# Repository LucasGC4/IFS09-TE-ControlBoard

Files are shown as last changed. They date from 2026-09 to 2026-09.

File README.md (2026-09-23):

isc-full-primary

# IFS09-TE-ControlBoard

Hardware design and KiCad schematics/PCB layout for the **Control Board (ECU Node)** of the **IFS09**, developed for the **ISC Formula Student Racing Team** (Season 2026/2027). This is a first onboarding project for the Electronics & Control subsystem — the board's mission is to become the vehicle's ECU node, reading dual CAN buses and analog/digital sensors from the AMPSEAL car harness.


[]()
[]()
[]()
[]()




---

## Getting started

1. Create a GitHub account if you don't have one yet.
2. Download and install [GitHub Desktop](https://desktop.github.com/) (beginner) or [Git CLI](https://git-scm.com/book/en/v2/Getting-Started-Installing-Git) (advanced).
3. Install [KiCad 10](https://www.kicad.org/download/) (or latest stable) and, if needed, link the team's shared library [`IFS-KicadLib`](https://github.com/isc-fs/IFS-KicadLib) for team-standard symbols and footprints.
4. Clone this repository to your machine:
   - **SSH:** `git@github.com:LucasGC4/IFS09-TE-ControlBoard.git`
   - **HTTPS:** `https://github.com/LucasGC4/IFS09-TE-ControlBoard.git`

---

## How we work with this repository

Following ISC's standard branching rules:

* **`main`** holds only validated releases. Never commit directly to it.
* Active design work happens on feature branches (`feat/<name>`, `fix/<name>`) created from `main`, merged back through a reviewed Pull Request.

```bash
git checkout main
git pull origin main
git checkout -b feat/your-feature-name
# ... work and commit ...
git commit -m "hw: add CAN2 split termination network"
git push origin feat/your-feature-name
```

Before opening a PR: verify **0 KiCad ERC/DRC errors** and export an updated `Schematics-X.X.pdf`.

---

## 1. Project Overview & System Purpose

The **IFS09 Control Board** is an automotive-grade microcontroller node connected to the car's 24V Low Voltage battery and both CAN communication buses, intended to read sensors and drive vehicle actuators.

```
+------------------------------------------------------------------------+
|                    IFS09 CAR WIRING HARNESS                            |
|   +24V LV Battery -- CAN1 -- CAN2 -- 2x Digital In -- 2x Analog In     |
+---------------------------------+----------------------------------------+
                                  |
                     AMPSEAL 14-Pin (J1, 1-776087-1)
                                  |
+---------------------------------v----------------------------------------+
|                       IFS09 CONTROL BOARD (ECU NODE)                    |
|                                                                          |
|  +24V --> [TSR 1-2450 Buck, U1] --> 5V --> [LM2936-3.3 LDO, U2] --> 3V3 |
|                                                                          |
|  CAN1 <--> [TCAN330, U3] --\                                           |
|                              >--- SPI/GPIO ---> [STM32H7A3IGTxQ, U4]    |
|  CAN2 <--> [TCAN330, U5] --/            (LQFP-176, 16 MHz osc. Y1)      |
|                                                                          |
|  Status LEDs (24V/5V/3.3V/Heartbeat) · SWD (J4) · UART+I2C (J2) · SPI (J3) |
+--------------------------------------------------------------------------+
```

### Key Highlights
* **Processing:** STM32H7A3IGTxQ (LQFP-176) with a 16 MHz active oscillator (`Y1`, XUX53) with isolated ground plane.
* **Power chain:** 24V → 5V via `U1` (TSR 1-2450 DC/DC module, fused with `F1` 2A), then 5V → 3.3V via `U2` (LM2936-3.3, TO-92).
* **CAN interfaces:** Two independent `TCAN330` transceivers (`U3` for CAN1, `U5` for CAN2), each with a 120 Ω bus termination resistor (`R5`, `R6`) and 100 nF decoupling.
* **Vehicle connector:** Single AMPSEAL-style 23-position header (`J1`, part `1-776087-1`) carries +24V, GND, CAN1, CAN2, and a 3V3 line to/from the harness.
* **Decoupling:** A bank of ~40 ceramic capacitors (mostly 100 nF, plus bulk caps) placed across the MCU's `VDD`/`VDDA` pins.
* **Diagnostics:** Four status LEDs (24V, 5V, 3.3V, Heartbeat) and four test points (`TP1`–`TP4`).
* **Debug/expansion headers:** `J4` (SWD), `J2` (UART + I²C), `J3` (SPI) — see pinout below.
* **Mechanical:** Four mounting holes (`H1`–`H4`), rounded-corner outline, 2-layer PCB (`F.Cu`/`B.Cu`).

---

## 2. Hardware Architecture & Schematic Design

The schematic export is available as [`Schematics.pdf`](Schematics.pdf), organized into labeled functional blocks matching the sections below.

### 2.1 Schematic Subsystem Breakdown

#### 1. Power Converters (24V → 5V → 3.3V)
* `F1` (2A fuse) protects the +24V input line.
* `U1` — **TSR 1-2450** DC/DC converter module steps 24V down to 5V, with `C3`/`C4` (10 µF) at input/output.
* `U2` — **LM2936-3.3 (TO-92)** LDO regulates 5V down to a clean 3.3V rail, with `C1`/`C2` (10 nF/100 nF) decoupling.

#### 2. Microcontroller (`U4` — STM32H7A3IGTxQ, LQFP-176)
* Clocked by a 16 MHz active oscillator (`Y1`, XUX53) placed in its own labeled section for ground isolation.
* Reset circuit: push button `SW1` with debounce capacitor `C11` (100 nF) and pull-up `R9` (10 kΩ) on `NRST`.
* `VCAP` pins filtered with `C6`/`C8` (2.2 µF).
* A large bank of decoupling capacitors (`C12`–`C55` range, mostly 100 nF, plus one 4.7 µF bulk cap) covers the MCU's power pins.

#### 3. Dual CAN Transceivers (`U3`, `U5` — TCAN330)
* `U3` interfaces `CAN1_TX`/`CAN1_RX` from the MCU to `CAN1_H`/`CAN1_L`, terminated by `R5` (120 Ω).
* `U5` interfaces `CAN2_TX`/`CAN2_RX` to `CAN2_H`/`CAN2_L`, terminated by `R6` (120 Ω).
* Each transceiver has its own 100 nF decoupling capacitor (`C9`, `C10`).

#### 4. Status LEDs & Test Points
* `D1`/`R1` (10 kΩ) — 24V rail indicator.
* `D2`/`R2` (1 kΩ) — 5V rail indicator.
* `D3`/`R3` (680 Ω) — 3.3V rail indicator.
* `D4`/`R4` (1 kΩ) — Heartbeat LED driven by the MCU.
* `TP1`–`TP4` — test points for the four rails/signals shown above.

---

## 3. PCB Layout & Physical Implementation

<p align="center">
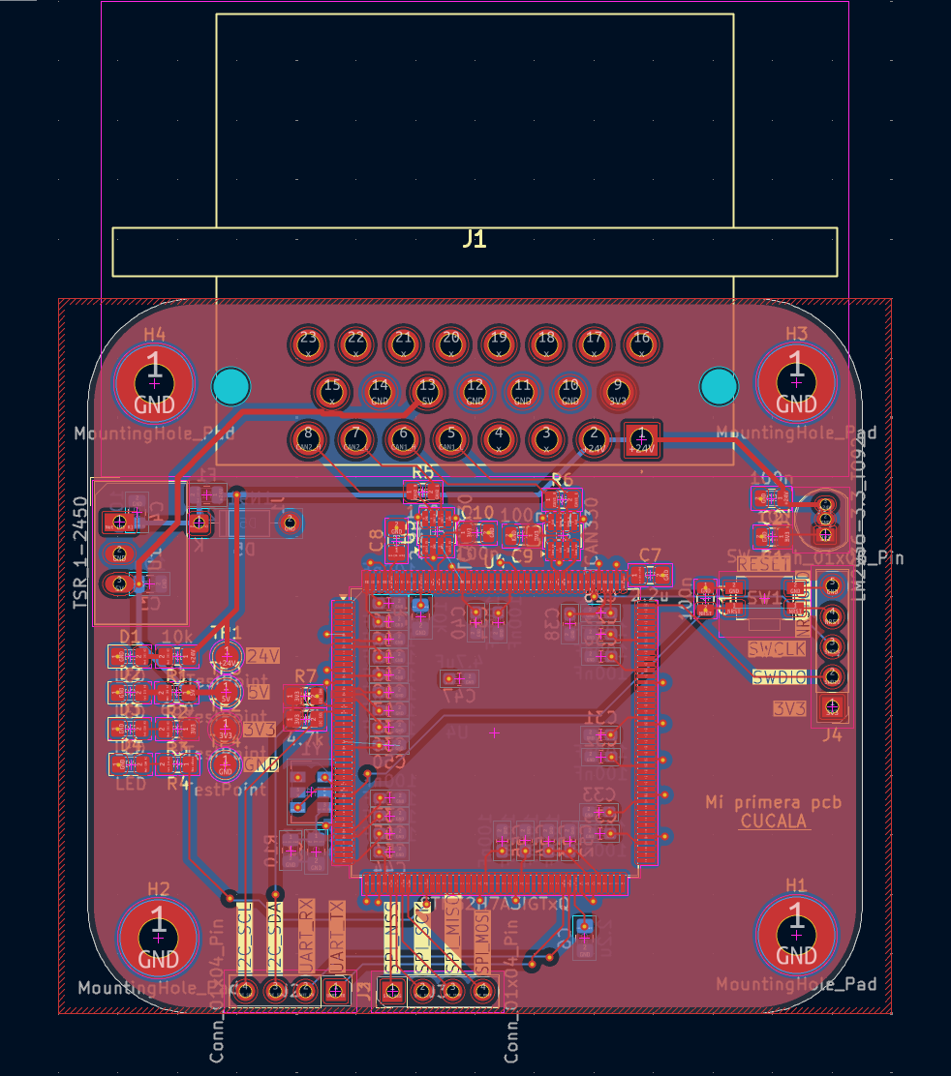
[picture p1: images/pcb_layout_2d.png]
IFS09 Control Board 2D PCB Layout
  
  &nbsp;&nbsp;&nbsp;&nbsp;
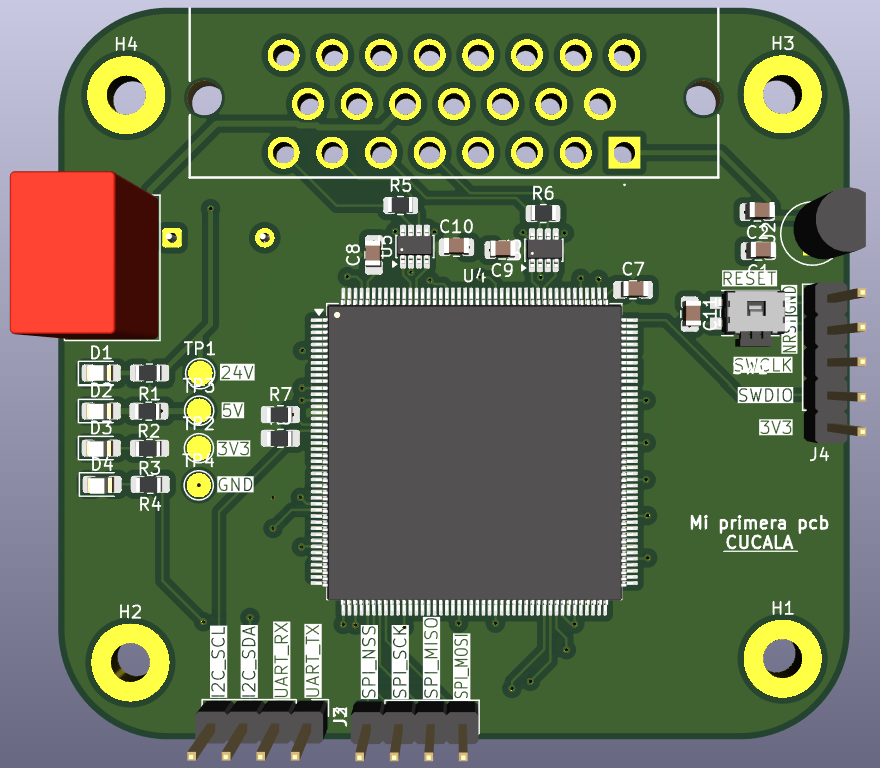
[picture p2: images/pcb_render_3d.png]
IFS09 Control Board 3D Render
  
</p>

* 2-layer board (`F.Cu` / `B.Cu`), rounded-corner outline, four M3-class mounting holes (`H1`–`H4`) at the corners.
* `J1` (AMPSEAL) is placed along the top edge for direct harness mating; the MCU (`U4`) sits centrally with debug/expansion headers (`J2`, `J3`, `J4`) broken out along the bottom edge.

---

## 4. Pinout & Hardware Interfacing

### 4.1 Vehicle Connector — `J1` (`1-776087-1`, AMPSEAL-style, 23-position)

| Pin(s) | Signal | Notes |
| :--- | :--- | :--- |
| 1, 2 | `+24V` | Battery input (tied together) |
| 5 | `CAN1_L` | CAN Bus 1 |
| 6 | `CAN1_H` | CAN Bus 1 |
| 7 | `CAN2_L` | CAN Bus 2 |
| 8 | `CAN2_H` | CAN Bus 2 |
| 9 | `3V3` | 3.3V line to/from harness |
| 10, 11 | `GND` | Ground |
| 13 | `5V` | 5V output |
| 14 | `GND` | Ground |
| 3, 4, 15–23 | *NC* | Not connected in this revision |

### 4.2 Debug & Expansion Headers

| Header | Type | Pin 1 | Pin 2 | Pin 3 | Pin 4 | Pin 5 |
| :--- | :--- | :--- | :--- | :--- | :--- | :--- |
| `J4` | SWD (5-pin) | `3V3` | `SWDIO` | `SWCLK` | `NRST` | `GND` |
| `J2` | UART + I²C (4-pin) | `UART_TX` | `UART_RX` | `I2C_SDA` | `I2C_SCL` | — |
| `J3` | SPI (4-pin) | `SPI_NSS` | `SPI_SCK` | `SPI_MISO` | `SPI_MOSI` | — |

> I²C lines (`I2C_SDA`/`I2C_SCL`) are pulled up to 3V3 via `R7`/`R8` (4.7 kΩ each).

---

## 5. Repository Structure

```
IFS09-TE-ControlBoard/
├── images/                                  # PCB layout/render exports
│   ├── pcb_layout_2d.png                    # 2D PCB Layout Routing View
│   └── pcb_render_3d.png                    # 3D PCB Render Model
├── IFS09-ControlBoard/                      # KiCad Project Files (KiCad 10.x)
│   ├── IFS09-ControlBoard.kicad_pro         # Project Configuration
│   ├── IFS09-ControlBoard.kicad_sch         # Schematic Sheet
│   └── IFS09-ControlBoard.kicad_pcb         # PCB Layout & Netlist
├── WO_TE-IFS09-ControlBoard (1).pdf         # Work Order / onboarding brief (Rev 1.1)
├── Schematics.pdf                           # Exported schematic sheet
└── README.md                                # This file
```

> **Not yet in the repository:** a Design Report (`DR_TE-IFS09-ControlBoard.pdf`) and a `SW/` firmware folder — both are still pending, per the Work Order's submission checklist.

---

## 6. Formal Design Documents

| Document | File Link | Description | Status |
| :--- | :--- | :--- | :--- |
| **Work Order** | [📄 WO_TE-IFS09-ControlBoard (1).pdf](<WO_TE-IFS09-ControlBoard (1).pdf>) | Onboarding roadmap, requirements, and pinout brief (Rev 1.1). | **Released** |
| **Schematics** | [📄 Schematics.pdf](Schematics.pdf) | Exported schematic sheet. | Current |
| **Design Report** | *(not yet created)* | Component justifications, BOM, and post-assembly test results. | **Pending** |

---

## 7. Acceptance Testing Checklist (Post-Assembly Bench QA)

As defined in the Work Order, once the board is assembled:

1. **Passive short-circuit check:** resistance from each supply test point to `GND` must read **> 10 kΩ** before power-up.
2. **Power-up & regulation:** with a 24V bench supply (current-limited to 200 mA), verify `TP2` (5V) = 5.0 V ± 0.2 V and `TP3` (3.3V) = 3.3 V ± 0.05 V, and that all power LEDs light up.
3. **SWD detection & MCU flash:** connect ST-Link to `J4` and flash test firmware to blink the Heartbeat LED (`D4`).
4. **Dual CAN loopback:** connect `CAN1`/`CAN2` to a USB-CAN adapter (PCAN/CANable) and verify send/receive at 500 kbit/s with zero dropped frames.
5. **Bus probing:** check `SPI` (`J3`) and `UART`/`I2C` (`J2`) lines with an oscilloscope for clean signals.

---

## 8. Author & Credits

* **Subsystem:** Electronics & Control (CE)
* **Author:** Lucas García Cucala
* **Mentorship & Review:** Carlota Treviño, Félix González, Inés Pacheco, Andrés Sánchez de Ágreda
* **Team:** [ISC Formula Student Racing Team](https://www.comillas.edu/) — Universidad Pontificia Comillas (ICAI)
* **Season:** 2026 / 2027

---

*ISC Racing Team — IFS09 Electronics & Control Subsystem*

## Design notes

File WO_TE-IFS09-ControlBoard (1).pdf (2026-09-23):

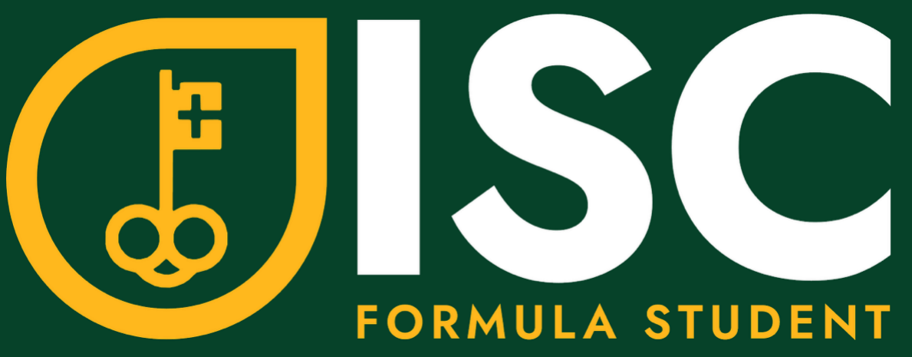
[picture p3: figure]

### Season 2026/2027

# Work Order – IFS09 Control Board

Department: Electronics & Control
Author: Andrés Sánchez, Carlota Treviño & Inés Pacheco Date: 3 September 2026
Revision: 1.1 (Onboarding Edition)

CONFIDENTIALITY NOTICE: the contents of this document are intended solely for use within the team and its members, may contain confidential or privileged information and may be legally protected from disclosure.

ISC Formula Student Racing Team © | Page 1
DOCUMENT ID: WO-IFS09-CTRL-001 | ELECTRONICS ONBOARDING & KICAD SCHEMATIC GUIDE

# 1. Welcome to ISC Electronics: The Journey from Mingo to Tronik

Welcome to the ISC Electronics & Control Subsystem! If you are reading this, your journey from the introductory recruitment phase ('Mingo') to designing real competition embedded electronic hardware for our IFS09 single-seater electric race car has officially begun. Don't worry if you have never designed a PCB before! This Work Order is designed as a comprehensive onboarding roadmap to guide you through KiCad, GitHub, and automotive PCB design practices.

## 1.1 The Two Pillars: Work Order (WO) vs. Design Report (DR)

In Formula Student, no board is ever manufactured without following our two-step engineering lifecycle:

- 1. The Work Order (WO): The engineering contract & requirement brief. It defines what the board must do, input voltages, connectors, and bench tests it must pass before you open KiCad.
- 2. The Design Report (DR): The technical defense document written after finishing your PCB in KiCad. It explains how you solved the requirements, why you chose specific component values, and presents your schematic exports, 2D/3D renders, and BOM before we order the PCB.

## 1.2 Team Dynamic & Feedback Loop

You are not expected to get every trace and pin assignment right on day one! We work in 1-week feedback loops where we review your progress, answer questions, and help you route. The objective of this first project is for you to become confident with KiCad, understand our Git workflow, and master good design habits before we move on to key vehicle boards like the ECU, the Telemetry Node, and the Dash (driver dashboard).

# 2. KiCad Setup & Component Libraries

Before opening KiCad, ensure you have the proper tools and libraries installed:

- KiCad 10 Download: Official open-source EDA suite. Download and install KiCad 10 (or latest stable) from https://www.kicad.org/download/
- Recommended Community Libraries: Open the Plugin and Content Manager in KiCad and install: (1) 4ms Kicad Libraries (audio/analog/DSP footprints) and (2) Alternate Kicad Library (AKL) for clean, modernized schematic symbols.

## 2.1 The Official Team Component Library: IFS-KicadLib

Our team maintains its own centralized repository containing verified symbols and footprints for all components used in our race cars (automotive connectors, STM32 microcontrollers, CAN transceivers, TVS diodes, and team-standard SMD passives):

- Repository Link: https://github.com/isc-fs/IFS-KicadLib

Golden Rule: Before searching for a symbol in KiCad's default libraries or making a custom footprint from scratch, ALWAYS check if it already exists in IFS-KicadLib!

- How to Link Symbols: Preferences -> Manage Symbol Libraries -> Global Libraries -> Add IFS-KicadLib.kicad_sym
- How to Link Footprints: Preferences -> Manage Footprint Libraries -> Global Libraries -> Add .pretty footprint folders

# 3. How to Work with GitHub (HW & SW in the Same Repository)

In automotive embedded systems, hardware and firmware are inseparable. A change in the hardware (e.g. reassigning a pin or changing a transceiver) immediately impacts the firmware running on that board. To ensure complete traceability, we store hardware design files and embedded firmware together in the same GitHub repository.

## 3.1 Mandatory Action: Create Your Own Repository for this Board

As your very first step in this onboarding project, you must create a dedicated GitHub repository of your own to host all your work on this board:

- Repository Naming: Name your repository following team standards: IFS09-CE-ControlBoard_<YourName> (or initials).
- Template Setup: Initialize it using the team template at https://github.com/isc-fs/plantilla or mirror the structure of IFS09-TE-TeleReceiver.
- Continuous Commits: Every time you add a subcircuit, place components, or write test firmware, commit and push your changes with clear messages.
- Share with Mentors: Share your repository link with Carlota, Félix, Inés, or Andrés so we can track your progress and give you feedback during our weekly reviews!

## 3.2 The Reference Model: IFS09-TE-TeleReceiver

Inspect our IFS09 Telemetry Receiver repository as the gold standard for this unified repository structure: https://github.com/isc-fs/IFS09-TE-TeleReceiver

## 3.3 Standard Repository File Structure

- docs/images/: Contains exported schematic previews, 2D PCB routing layers, and 3D mechanical renders.
- <Project_Name>/: Holds the KiCad project files (.kicad_pro, .kicad_sch, .kicad_pcb).
- SW/: Embedded firmware sketches, STM32CubeIDE project files, and hardware drivers.
- WO_<ID>_<BoardName>.pdf: Requirements, engineering brief, and test criteria.
- DR_<ID>_<BoardName>.pdf: Technical defense, calculations, BOM, and post-assembly test results.
- Schematics-<Version>.pdf: Latest high-resolution vector PDF export of the schematic sheets.

## 3.4 Git Branching & Pull Request Rules

- Branching: Main holds only validated releases. All active design occurs on feature branches (feat/<name>).
- Commit Messages: Use clear prefixes: 'hw: add 100nF decoupling capacitors' or 'sw: update CAN baud rate'.
- PR Checklist: Before opening a PR to dev/main, ensure 0 KiCad ERC errors, 0 DRC errors, and export an updated Schematics-X.X.pdf.

# 4. How to Start in KiCad: The Schematic Editor

When you open your KiCad project, click on the Schematic Editor (Editor de esquemas). This is where your design starts: here we define the electrical logic before routing physical copper tracks.

## 4.1 Essential Shortcuts & Right Sidebar Tools

- [Esc] Pointer / Selection: Select and inspect elements.
- [A] Add Symbol: (Op-amp triangle icon) Open the component library browser to search for parts.
- [W] Add Wire: (Wire icon) Draw electrical connection lines between symbol pins.
- [P] Add Power / GND: (Ground icon) Place power supply rails (+24V, +5V, +3V3) and ground nodes (GND).
- [L] Add Net Label: (Tag icon) Name an electrical net. Any two wires that share the same net label are electrically connected without needing crossing wires!
- [Q] No-Connect Flag: Mark intentionally unused microcontroller pins.

## 4.2 How to Choose and Place Components

- Resistors & Capacitors: Search for generic 'R' or 'C'. Place them and edit the value (e.g. 10k, 100nF, 4.7uF). Small SMD passives use 0603 or 0805 packages.
- External Elements: You don't place pushbuttons or screens directly on the board schematic if they are external to the PCB! Instead, place the connector that will mate with the external wire harness and use net labels (e.g., BTN_SELECT, I2C_SCL).

# 5. The Mission: IFS09 Control Board Architecture

You will design an automotive-grade IFS09 Control Board (ECU Node). In our race car, this board acts as an intelligent microcontroller node connected to the car's 24V Low Voltage battery and two CAN communication networks to read sensors and drive vehicle actuators.

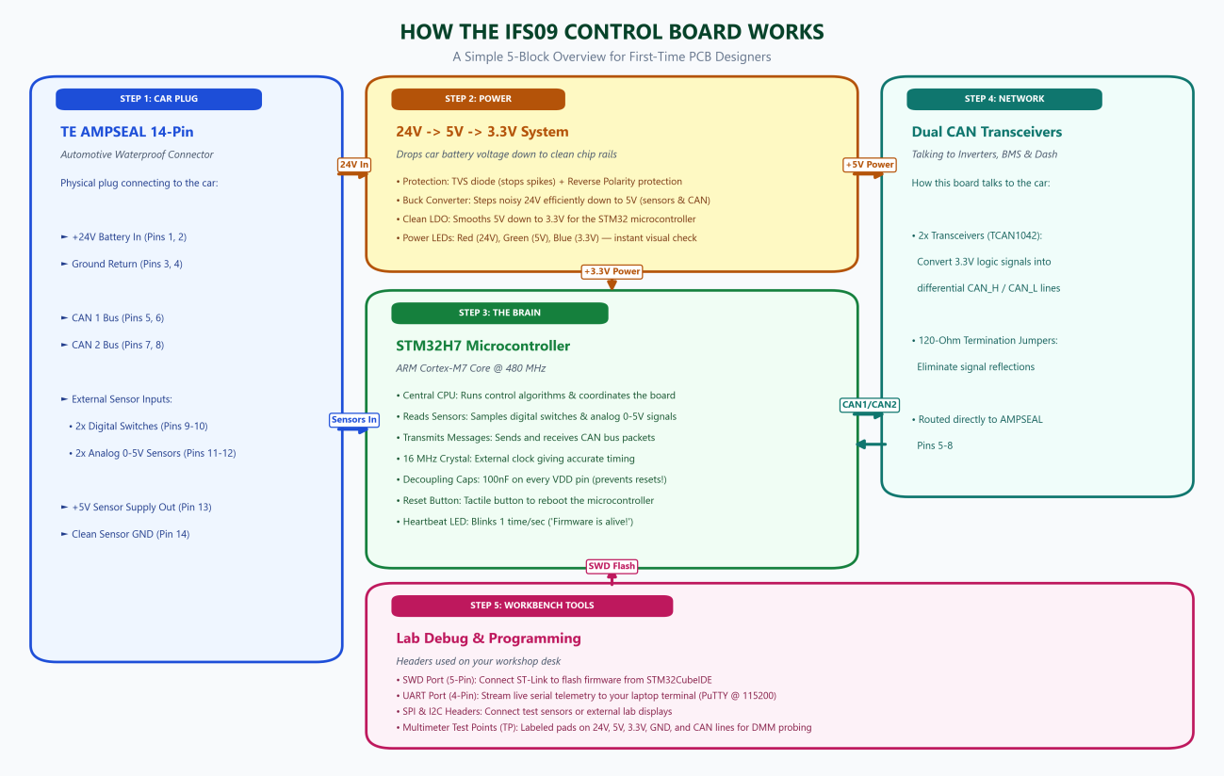
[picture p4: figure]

Figure 5.1: IFS09 Control Board Functional Block Diagram

## 5.1 Architecture Overview & Signal Flow

The board architecture is partitioned into five distinct, color-coded functional domains designed to ensure clean signal routing, eliminate ground loops, and prevent high-voltage noise from disturbing sensitive microcontroller operations:

- Step 1: Car Plug (TE AMPSEAL 14-Pin - Royal Blue): The sole physical interface connecting the PCB to the race car wiring harness. It receives the 24V low-voltage battery power, exposes dual CAN bus interfaces, brings in external analog and digital sensor signals, and provides a regulated 5V sensor power rail and clean sensor ground reference.
- Step 2: Power System (24V -> 5V -> 3.3V - Warm Gold): Converts the noisy 24V automotive battery into clean, stable DC voltage rails. It includes an input transient suppression stage (TVS diode and reverse-polarity protection), an efficient step-down Buck converter (24V to 5V) for high-current loads and external sensors, and a low-noise linear LDO regulator (5V to 3.3V) dedicated strictly to the STM32H7 core and sensitive logic.
- Step 3: The Brain (STM32H7 Microcontroller - Fresh Green): The high-performance computational core (ARM Cortex-M7 @ 480 MHz). It executes vehicle control firmware, samples analog inputs, manages dual CAN channels, and provides a visual 1 Hz heartbeat indicator to confirm normal system operation.
- Step 4: Car Network (Dual CAN Transceivers - Teal Green): Two dedicated automotive CAN transceivers (TCAN1042) that translate 3.3V logic signals from the microcontroller into rugged differential CAN_H and CAN_L communication buses, featuring 120-ohm split termination networks to eliminate signal reflections.
- Step 5: Workbench Tools (Lab Debug & Programming - Rose Pink): Workshop development headers including a 5-pin SWD programming port for ST-Link, a 4-pin UART header for live serial telemetry streaming to a PC, SPI/I2C expansion headers, and dedicated surface test points for multimeter and oscilloscope diagnostics.

## 5.2 Functional Block Descriptions

- Block 1: Car Plug (AMPSEAL 14): All off-board connections route through TE Connectivity 776262-1: dual power pins (+24V, GND), dual CAN channels (CAN1, CAN2), 2x digital inputs, 2x 0-5V analog inputs, and a regulated +5V sensor supply with clean ground.
- Block 2: Power Regulation Tree: Features TVS surge clamping, reverse polarity P-MOSFET, switching buck (24V -> 5V) with >85% efficiency, low-noise LDO (5V -> 3.3V), and visual power LEDs (Red 24V, Green 5V, Blue 3.3V).
- Block 3: The Brain (STM32H7 MCU): STM32H7 processor with 16 MHz HSE crystal oscillator, 100 nF ceramic decoupling on every power pin, hardware reset button, and 1 Hz Heartbeat LED on PB0.
- Block 4: Car Network (Dual CAN): Dual TCAN1042 transceivers separating powertrain (Inverters/BMS) and telemetry/sensors with 120-ohm split termination and ESD diode arrays.
- Block 5: Workbench Tools (Lab Debug): Standard 2.54 mm pin headers for SWD firmware flashing (ST-Link), UART serial monitor (115200 baud), SPI/I2C expansion, and surface test points for multimeter verification.

# 6. Functional Subcircuits & Design Requirements

Break your schematic into clear functional subcircuits. For each block, pay close attention to what is VITAL (mandatory) and the EXTRA (automotive best practices).

## 6.1 Power Supply Subsystem (24V -> 5V -> 3.3V)

Qué hace: Receives the 24V DC supply from the car's Low Voltage battery, suppresses severe electrical noise and load-dump voltage spikes, and generates a regulated 5V rail for sensors and transceivers, plus a clean 3.3V rail for the microcontroller core.

- VITAL: High-efficiency step-down converter (input >= 40V, output >= 1.5A) with power inductor and filter caps. (Tip: You can use a discrete synchronous buck like TPS54302 or the integrated OKI-78SR switching regulator module used in previous team designs!). 5V -> 3.3V clean LDO regulator (LM1117-3.3 / AP2112K). Bulk capacitors (10-47 µF) at the input/output of each regulator.
- EXTRA: High-power bidirectional TVS diode (SMCJ30A or SMBJ28A) across 24V input to swallow inductive spikes. P-MOSFET reverse polarity protection circuit. Resettable PPTC polyfuse on 24V line. LC pi-filter on MCU analog VDDA pin.

## 6.2 Microcontroller Unit (MCU — STM32H7)

Qué hace: The central computational brain of the board. It executes the control firmware, samples analog sensors, manages dual CAN buses, and commands external actuators.

- VITAL: STM32H7 series MCU (e.g. STM32H733 / H723). External 16 MHz or 25 MHz HSE crystal oscillator with matched load capacitors (12-18 pF). Reset push button with 100nF cap and 10k pull-up to 3.3V. Decoupling Capacitors (Rule #1 of Microcontrollers): Place a 100 nF ceramic

capacitor on EVERY SINGLE VDD and VDDA pin as close as physically possible with direct ground vias!
- EXTRA: BOOT0 pull-down resistor with jumper to 3.3V for DFU bootloader flashing. 1 µF and 10 µF ceramic reservoir capacitors near high-speed supply rails.

## 6.3 Dual CAN Bus Interfaces (CAN1 & CAN2)

Qué hace: Connects the board to the vehicle's high-speed differential CAN communication networks (Inverters, BMS, Dashboard, and Telemetry).

- VITAL: 2x automotive CAN/CAN-FD transceivers (TCAN1042 / MCP2562 / SN65HVD230) powered from 5V with 3.3V logic compatibility. 120-ohm bus termination on each channel selectable via 2-pin jumper. 100 nF decoupling capacitor across VCC/GND on each transceiver.
- EXTRA: Split termination network (two 60-ohm resistors in series with 4.7 nF cap to GND) for superior common-mode noise suppression. Automotive TVS diode arrays (PESD2CAN or NUP2105L) on CAN_H and CAN_L lines.

## 6.4 Automotive Connector: TE AMPSEAL 14-Pin Header

Qué hace: Rugged, waterproof physical interface connecting the PCB to the vehicle wiring harness.

Pin # | Signal Name | What it connects to
1, 2 | +24V_IN | 24V Power Input from LV Battery (Two pins in parallel for current capacity)
3, 4 | GND_PWR | Main Power Ground Return Plane
5, 6 | CAN1_H / CAN1_L | CAN Bus 1 (Vehicle Inverter & Primary Telemetry)
7, 8 | CAN2_H / CAN2_L | CAN Bus 2 (Sensors & Safety Subsystem)
9, 10 | DIG_IN1 / DIG_IN2 | Clamped Digital Inputs for sensors/switches
11, 12 | ANALOG_IN1 / ANALOG_IN2 | 0-5V Analog Sensor Inputs (with RC filter & clamping diodes)
13 | 5V_OUT | Regulated 5V output to power external sensors
14 | GND_SIG | Clean analog signal ground reference

## 6.5 Expansion & Debug Headers (2.54 mm Pitch)

Qué hace: Allows bench programming, firmware debugging, and hardware expansion in the workshop.

- VITAL: SWD Programming Header (5-pin: 3V3, SWDIO, SWCLK, NRST, GND) for ST-Link flashing. Without this, your board is just an expensive decorative paperweight!

- EXTRA: SPI Header (6-pin), I2C Header (4-pin with 4.7k pull-up resistors), UART Header (4-pin) for serial debugging, and 8-pin digital GPIO header.

## 6.6 Diagnostic Status LEDs & Test Points

Qué hace: Allows anyone working on the car or in the workshop to instantly diagnose the board's health without needing an oscilloscope.

- Diagnostic LEDs: Power supply LEDs: Red on 24V (>=4.7k resistor), Green on 5V (1.5k), Blue on 3.3V (1k). MCU Heartbeat LED on PB0 (blinks once per second proving firmware is alive). CAN activity LEDs on transceiver TX/RX lines.
- Test Points Everywhere: Labeled test pads (min 1.0 mm pad diameter) for TP_24V, TP_5V, TP_3V3, TP_GND, TP_CAN1_H, TP_CAN1_L, TP_NRST, TP_SWDIO, TP_SWCLK.

# 7. Acceptance Testing Checklist (Post-Assembly Bench

QA)

When your manufactured board arrives from the assembly factory, you will follow this step-by-step verification checklist:

- Step 1 (Passive Short-Circuit Check): Measure resistance across supply test points to GND with a multimeter. All readings must be > 10 kΩ before power-up (no solder shorts).
- Step 2 (Power-Up & Regulation): Connect 24V bench power supply (current-limited to 200 mA). Verify V(TP_5V) = 5.0V ± 0.2V, V(TP_3V3) = 3.3V ± 0.05V, and check that all power LEDs illuminate.
- Step 3 (SWD Detection & MCU Flash): Connect ST-Link to SWD header. Detect target in STM32CubeProgrammer and flash test firmware to blink the Heartbeat LED (PB0).
- Step 4 (Dual CAN Loopback): Connect CAN1 & CAN2 to a USB-CAN adapter (PCAN / CANable) and verify sending and receiving packets at 500 kbit/s with zero dropped frames.
- Step 5 (Bus Probing): Probe SPI, I2C, and UART with an oscilloscope to verify clean square wave signals.

# 8. What You Need to Submit: The Design Report

Once your schematic and PCB routing pass KiCad DRC and ERC with 0 errors, you will submit a formal Design Report containing:

- 1. Executive Summary: Brief functional overview of your board and its role on the car.
- 2. Component Calculations & Justifications: Buck converter component selection (inductor saturation current, diode rating, ripple calculation) and decoupling capacitor network.
- 3. Schematic Export: Clean, high-resolution vector PDF schematic export (Schematics-1.0.pdf).
- 4. PCB Layout Showcase: 2D layout captures showing the bottom ground plane and 3D renders showing mechanical clearance for the AMPSEAL connector.
- 5. Bill of Materials (BOM): Complete spreadsheet with manufacturer part numbers (MPN), component packages, and supplier sourcing links.

# 9. Need Help? The Electronics Team is Here!

Remember: Nobody expects you to know everything on day one! Designing your first PCB is a collaborative learning experience, and asking questions is how every veteran on this team got started.

Whenever you get stuck on a circuit, have doubts about component footprints, or want someone to review your schematic before routing, reach out to your mentors:

- • Carlota Treviño
- • Félix González
- • Inés Pacheco
- • Andrés Sánchez de Ágreda

You can find us in the ICAI workshop, on the team WhatsApp group, or by mentioning us during weekly meetings. Enjoy the journey from Mingo to Tronik!

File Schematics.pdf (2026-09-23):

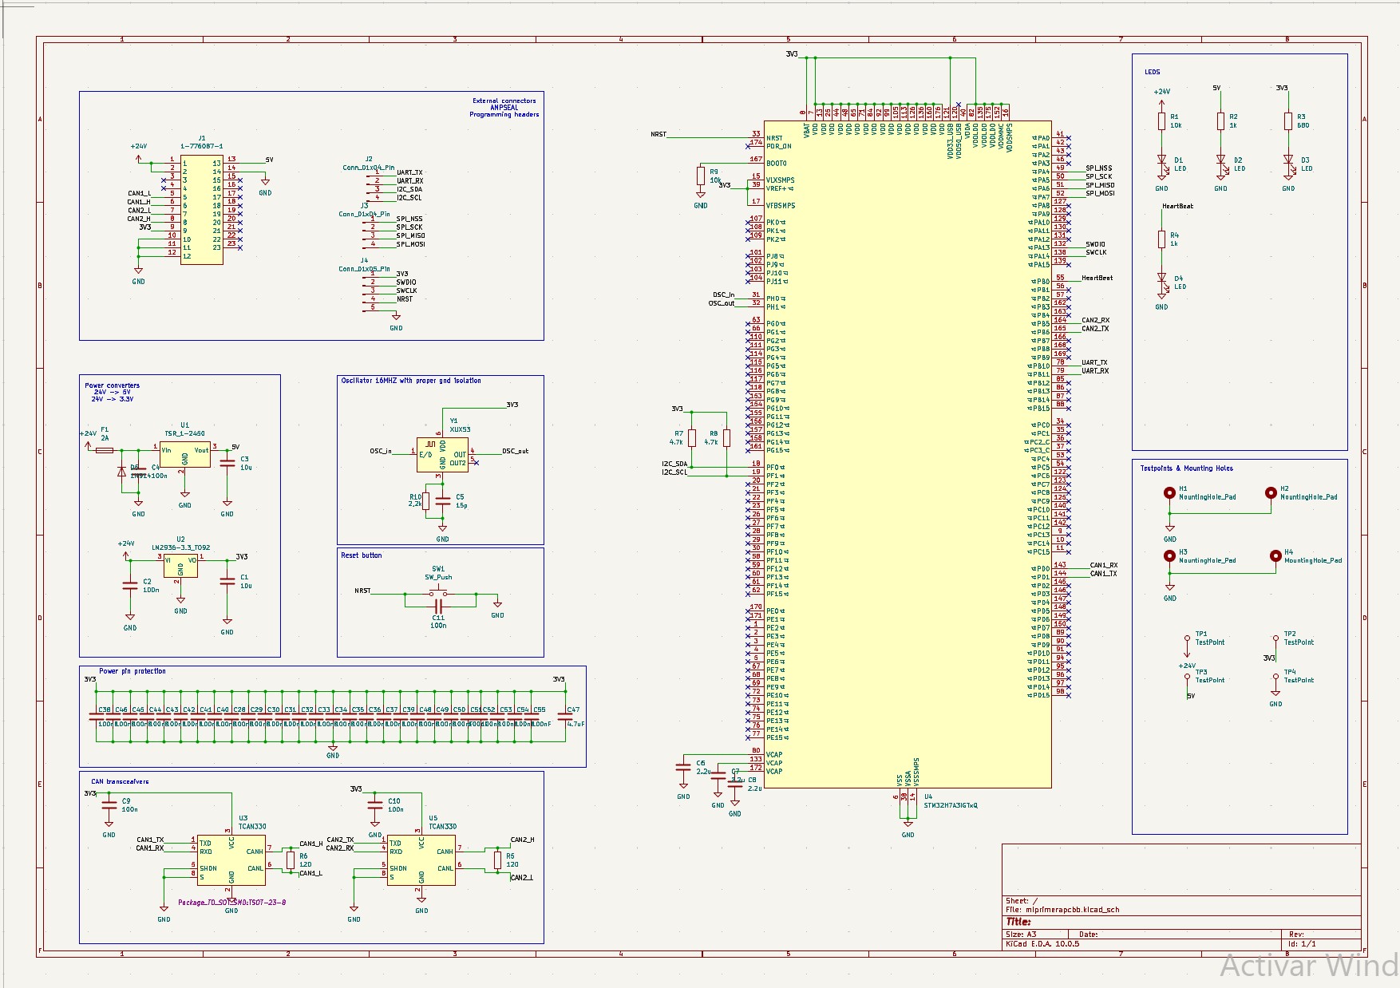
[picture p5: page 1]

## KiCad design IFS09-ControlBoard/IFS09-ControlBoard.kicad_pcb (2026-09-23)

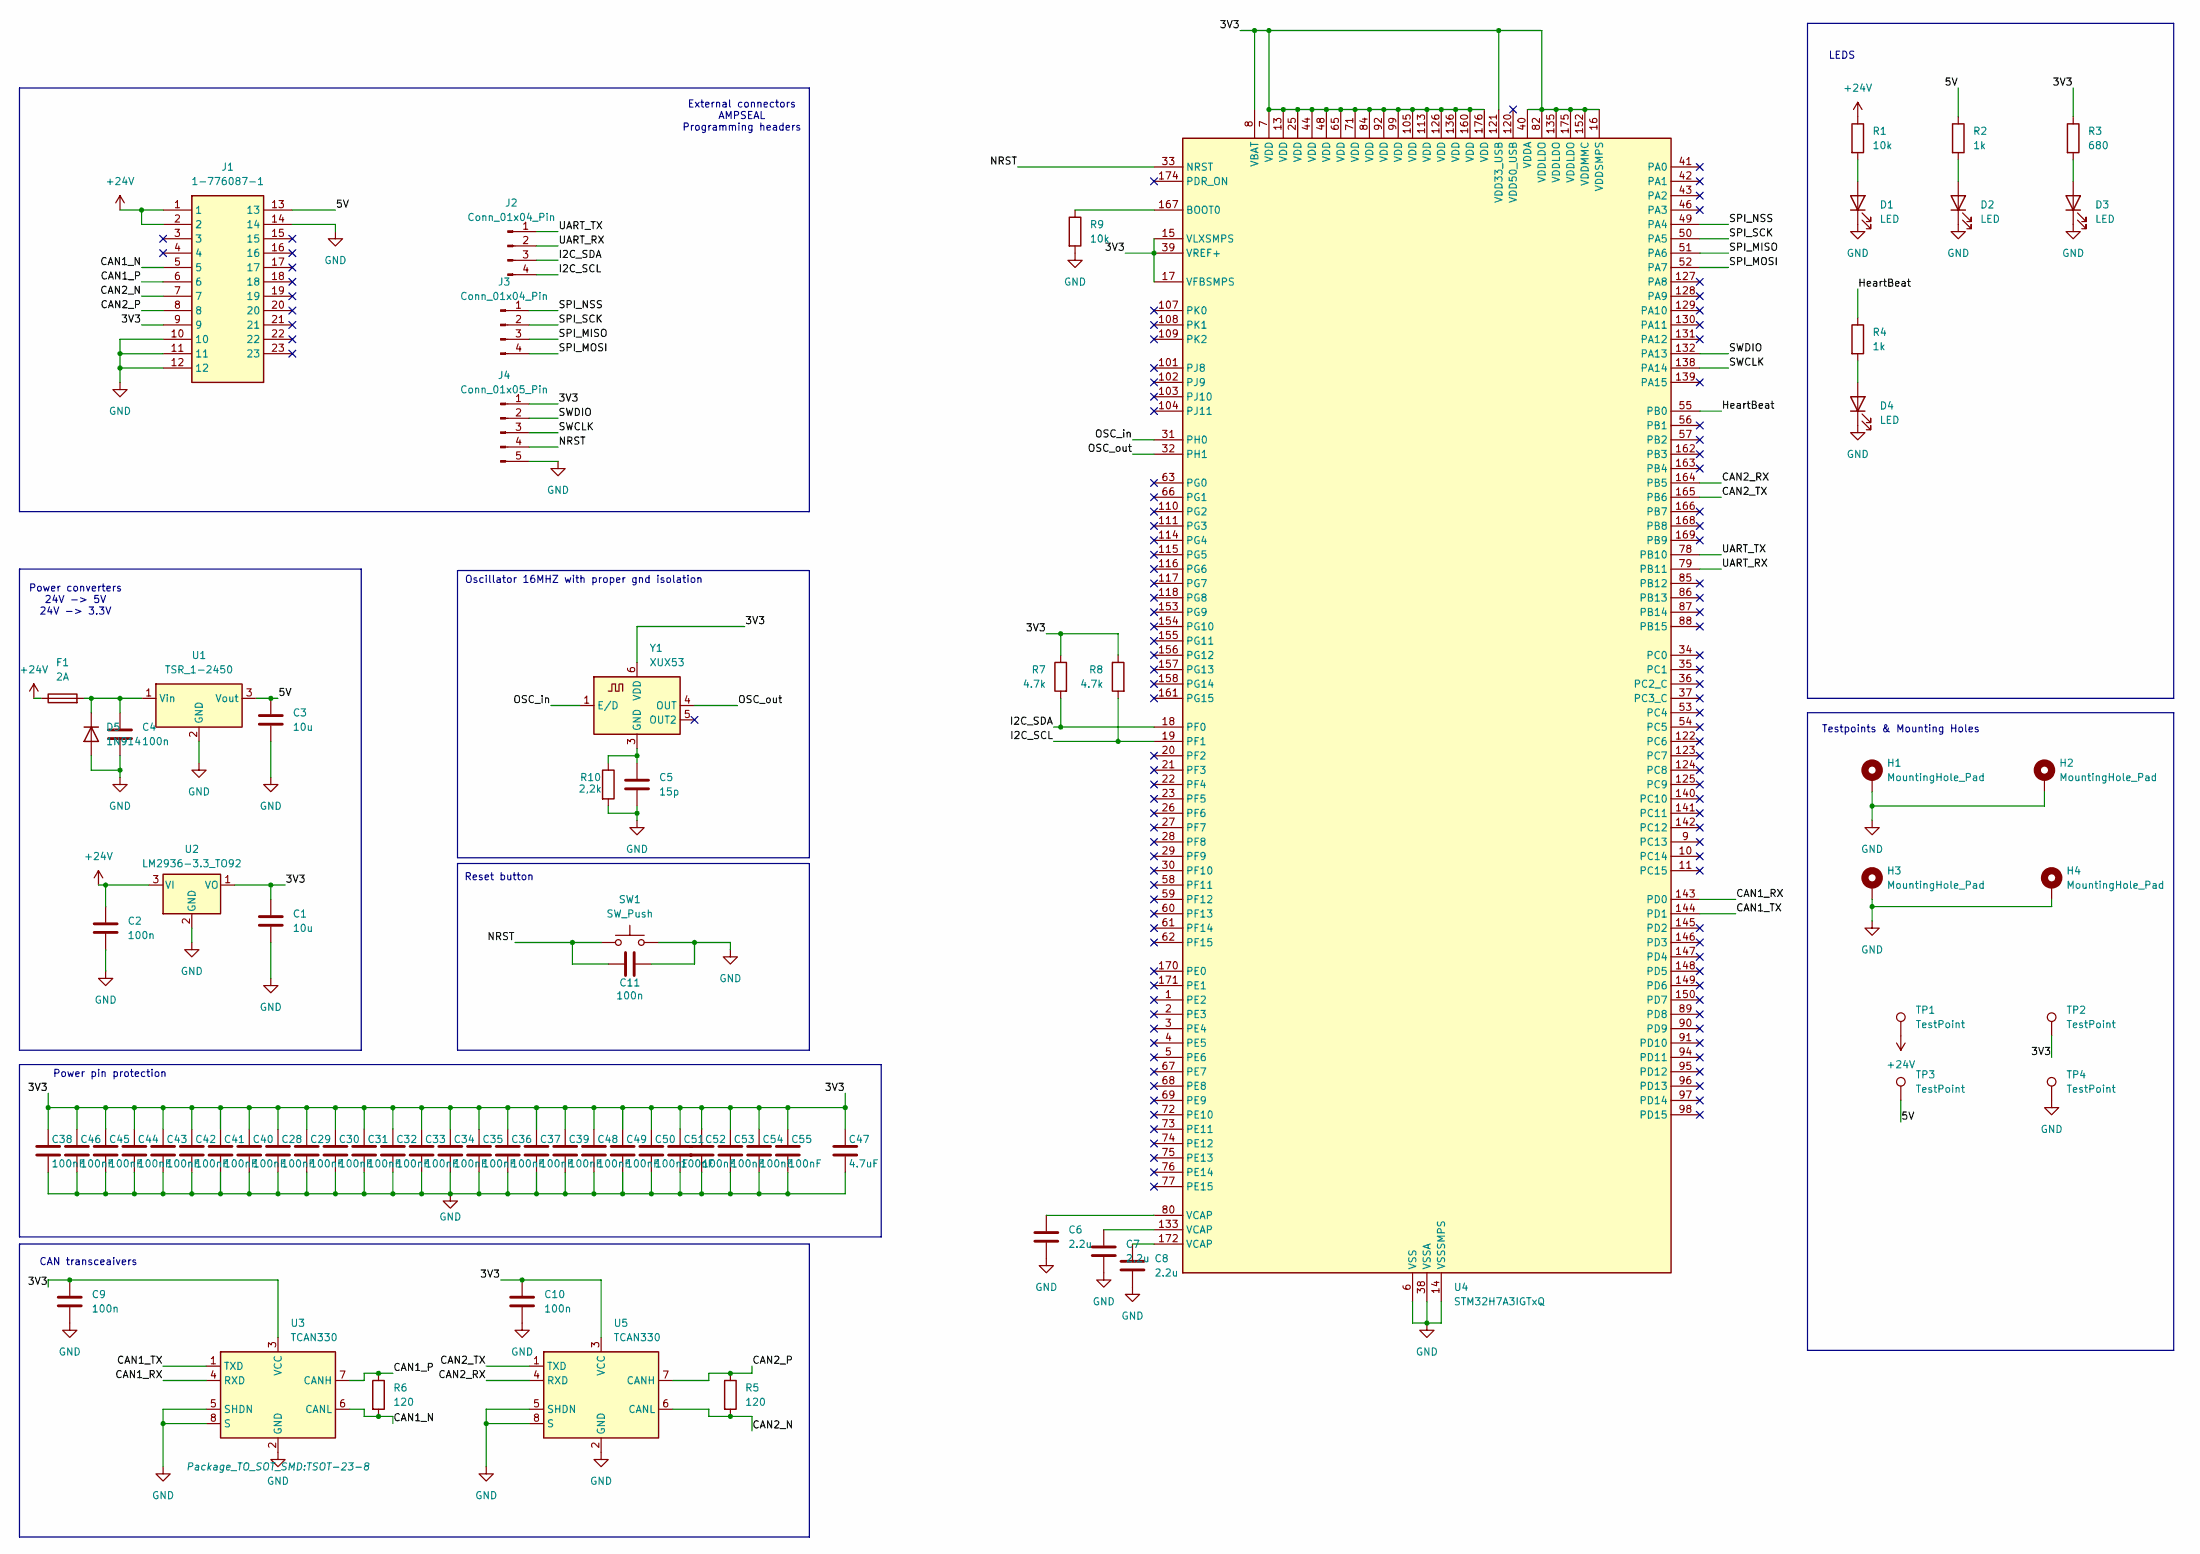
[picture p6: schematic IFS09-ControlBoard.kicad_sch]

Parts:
C1, C3: 10u; C_0805_2012Metric
C2, C4, C9, C10, C11: 100n; C_0805_2012Metric
C5: 15p; C_0805_2012Metric_Pad1.18x1.45mm_HandSolder
C6, C7, C8: 2.2u; C_0805_2012Metric_Pad1.18x1.45mm_HandSolder
C28, C29, C30, C31, C32, C33, C34, C35, C36, C37, C38, C39, C40, C41, C42, C43, C44, C45, C46, C48, C49, C50, C51, C52, C53, C54, C55: 100nF; C_0603_1608Metric_Pad1.08x0.95mm_HandSolder
C47: 4.7uF; C_0603_1608Metric_Pad1.08x0.95mm_HandSolder
D1, D2, D3, D4: LED; LED_0805_2012Metric_Pad1.15x1.40mm_HandSolder
D5: 1N914; D_DO-35_SOD27_P7.62mm_Horizontal
F1: 2A; Fuse_0805_2012Metric
H1, H2, H3, H4: MountingHole_Pad; MountingHole_3.2mm_M3_Pad
J1: 1-776087-1; 17760871; Mouser Part Number 571-1-776087-1
J2, J3: Conn_01x04_Pin; PinHeader_1x04_P2.54mm_Vertical
J4: Conn_01x05_Pin; PinHeader_1x05_P2.54mm_Vertical
R1, R9: 10k; R_0805_2012Metric_Pad1.20x1.40mm_HandSolder
R2, R4: 1k; R_0805_2012Metric_Pad1.20x1.40mm_HandSolder
R3: 680; R_0805_2012Metric_Pad1.20x1.40mm_HandSolder
R5, R6: 120; R_0805_2012Metric
R7, R8: 4.7k; R_0805_2012Metric_Pad1.20x1.40mm_HandSolder
R10: 2,2k; R_0805_2012Metric
SW1: SW_Push; Panasonic_EVQPUK_EVQPUB
TP1, TP2, TP3, TP4: TestPoint; TestPoint_Pad_D2.0mm
U1: TSR_1-2450; Converter_DCDC_TRACO_TSR-1_THT
U2: LM2936-3.3_TO92; TO-92_Inline
U3, U5: TCAN330; TSOT-23-8
U4: STM32H7A3IGTxQ; LQFP-176_24x24mm_P0.5mm
Y1: XUX53; Oscillator_SMD_IDT_JS6-6_5.0x3.2mm_P1.27mm

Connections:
+24V: C2.1, F1.1, J1.1, J1.2, R1.1, TP1.1 (1_1), U2.3 (VI)
/3V3: C1.1, C9.1, C10.1, C28.1, C29.1, C30.1, C31.1, C32.1, C33.1, C34.1, C35.1, C36.1, C37.1, C38.1, C39.1, C40.1, C41.1, C42.1, C43.1, C44.1, C45.1, C46.1, C47.1, C48.1, C49.1, C50.1, C51.1, C52.1, C53.1, C54.1, C55.1, J1.9, J4.1, R3.1, R7.1, R8.1, TP2.1 (1_1), U2.1 (VO), U3.3 (VCC), U4.7 (VDD), U4.8 (VBAT), U4.13 (VDD), U4.15 (VLXSMPS), U4.16 (VDDSMPS), U4.17 (VFBSMPS), U4.25 (VDD), U4.39 (VREF+), U4.40 (VDDA), U4.44 (VDD), U4.48 (VDD), U4.65 (VDD), U4.71 (VDD), U4.82 (VDDLDO), U4.84 (VDD), U4.92 (VDD), U4.99 (VDD), U4.105 (VDD), U4.113 (VDD), U4.121 (VDD33_USB), U4.126 (VDD), U4.135 (VDDLDO), U4.136 (VDD), U4.152 (VDDMMC), U4.160 (VDD), U4.175 (VDDLDO), U4.176 (VDD), U5.3 (VCC), Y1.6 (VDD)
/5V: C3.1, J1.13, R2.1, TP3.1 (1_1), U1.3 (Vout)
/CAN1_N: J1.5, R6.2, U3.6 (CANL)
/CAN1_P: J1.6, R6.1, U3.7 (CANH)
/CAN1_RX: U3.4 (RXD), U4.143 (PD0)
/CAN1_TX: U3.1 (TXD), U4.144 (PD1)
/CAN2_N: J1.7, R5.2, U5.6 (CANL)
/CAN2_P: J1.8, R5.1, U5.7 (CANH)
/CAN2_RX: U4.164 (PB5), U5.4 (RXD)
/CAN2_TX: U4.165 (PB6), U5.1 (TXD)
/HeartBeat: R4.1, U4.55 (PB0)
/I2C_SCL: J2.4, R8.2, U4.19 (PF1)
/I2C_SDA: J2.3, R7.2, U4.18 (PF0)
/NRST: C11.2, J4.4, SW1.1, U4.33 (NRST)
/OSC_in: U4.31 (PH0), Y1.1 (E/D)
/OSC_out: U4.32 (PH1), Y1.4 (OUT)
/SPI_MISO: J3.3, U4.51 (PA6)
/SPI_MOSI: J3.4, U4.52 (PA7)
/SPI_NSS: J3.1, U4.49 (PA4)
/SPI_SCK: J3.2, U4.50 (PA5)
/SWCLK: J4.3, U4.138 (PA14)
/SWDIO: J4.2, U4.132 (PA13)
/UART_RX: J2.2, U4.79 (PB11)
/UART_TX: J2.1, U4.78 (PB10)
GND: C1.2, C2.2, C3.2, C4.2, C5.2, C6.2, C7.2, C8.2, C9.2, C10.2, C11.1, C28.2, C29.2, C30.2, C31.2, C32.2, C33.2, C34.2, C35.2, C36.2, C37.2, C38.2, C39.2, C40.2, C41.2, C42.2, C43.2, C44.2, C45.2, C46.2, C47.2, C48.2, C49.2, C50.2, C51.2, C52.2, C53.2, C54.2, C55.2, D1.1 (K), D2.1 (K), D3.1 (K), D4.1 (K), D5.2 (A), H1.1 (1_1), H2.1 (1_1), H3.1 (1_1), H4.1 (1_1), J1.10, J1.11, J1.12, J1.14, J4.5, R9.2, R10.2, SW1.2, TP4.1 (1_1), U1.2 (GND), U2.2 (GND), U3.2 (GND), U3.5 (SHDN), U3.8 (S), U4.6 (VSS), U4.12 (VSS), U4.14 (VSSSMPS), U4.24 (VSS), U4.38 (VSSA), U4.45 (VSS), U4.47 (VSS), U4.64 (VSS), U4.70 (VSS), U4.81 (VSS), U4.83 (VSS), U4.93 (VSS), U4.100 (VSS), U4.106 (VSS), U4.112 (VSS), U4.119 (VSS), U4.134 (VSS), U4.137 (VSS), U4.151 (VSS), U4.159 (VSS), U4.173 (VSS), U5.2 (GND), U5.5 (SHDN), U5.8 (S)
unnamed: C6.1, U4.80 (VCAP)
unnamed: C7.1, U4.133 (VCAP)
unnamed: C8.1, U4.172 (VCAP)
unnamed: D1.2 (A), R1.2
unnamed: D2.2 (A), R2.2
unnamed: D3.2 (A), R3.2
unnamed: D4.2 (A), R4.2
unnamed: C4.1, D5.1 (K), F1.2, U1.1 (Vin)
unnamed: R9.1, U4.167 (BOOT0)
unnamed: C5.1, R10.1, Y1.3 (GND)

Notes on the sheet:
Power converters 24V -> 5V 24V -> 3.3V
Power pin protection
Testpoints & Mounting Holes
Oscillator 16MHZ with proper gnd isolation
Reset button
CAN transceaivers
External connectors AMPSEAL Programming headers
LEDS

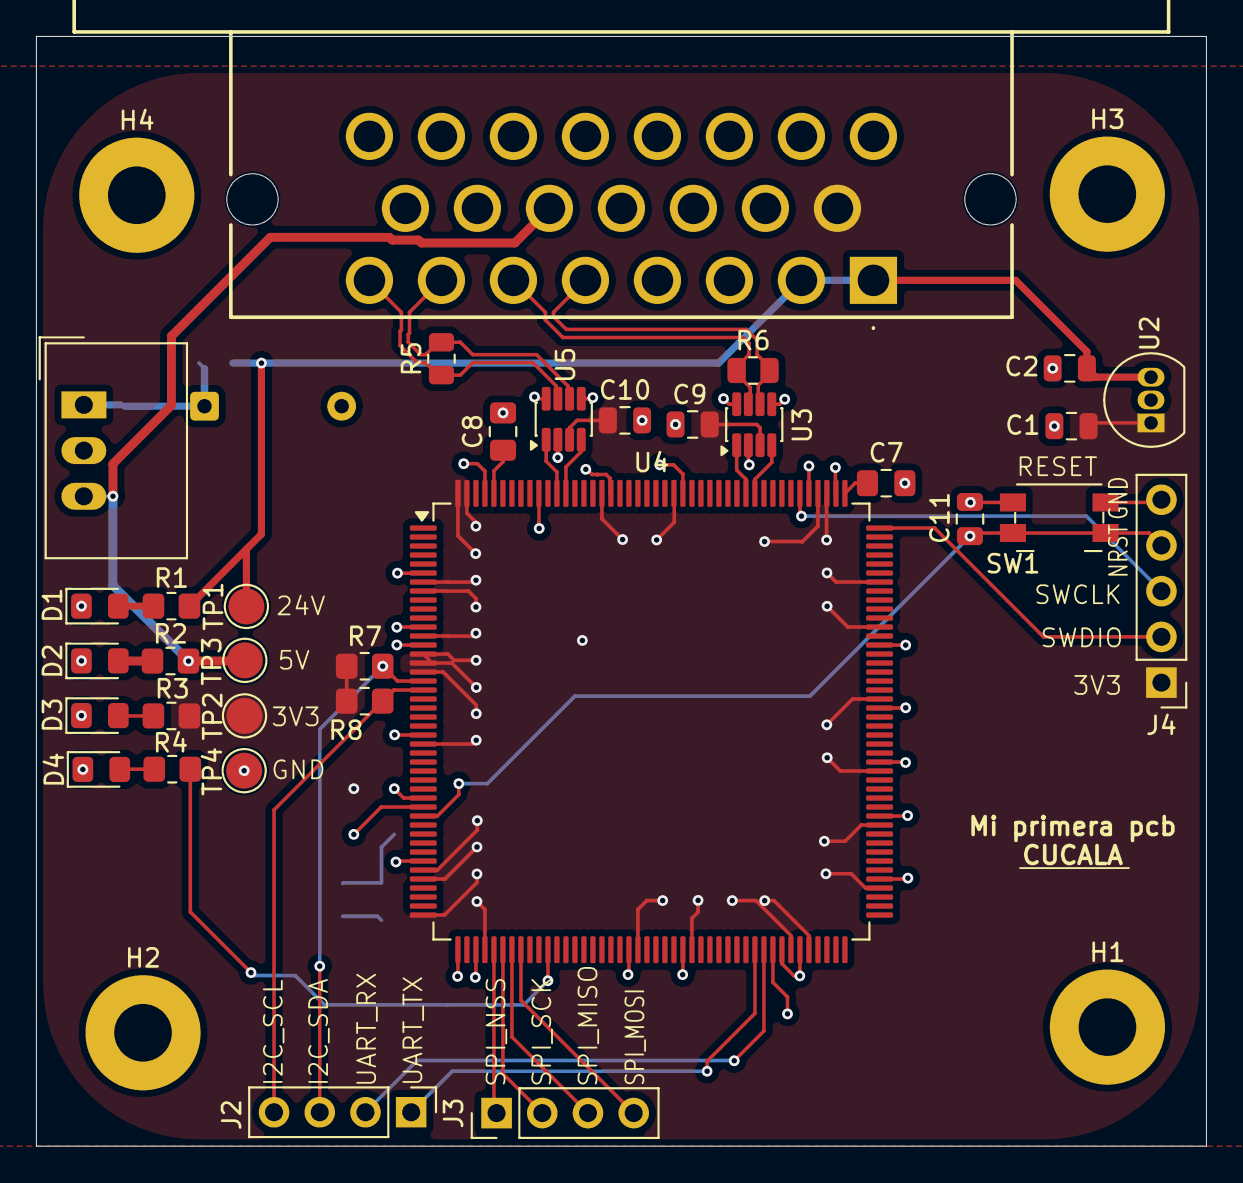
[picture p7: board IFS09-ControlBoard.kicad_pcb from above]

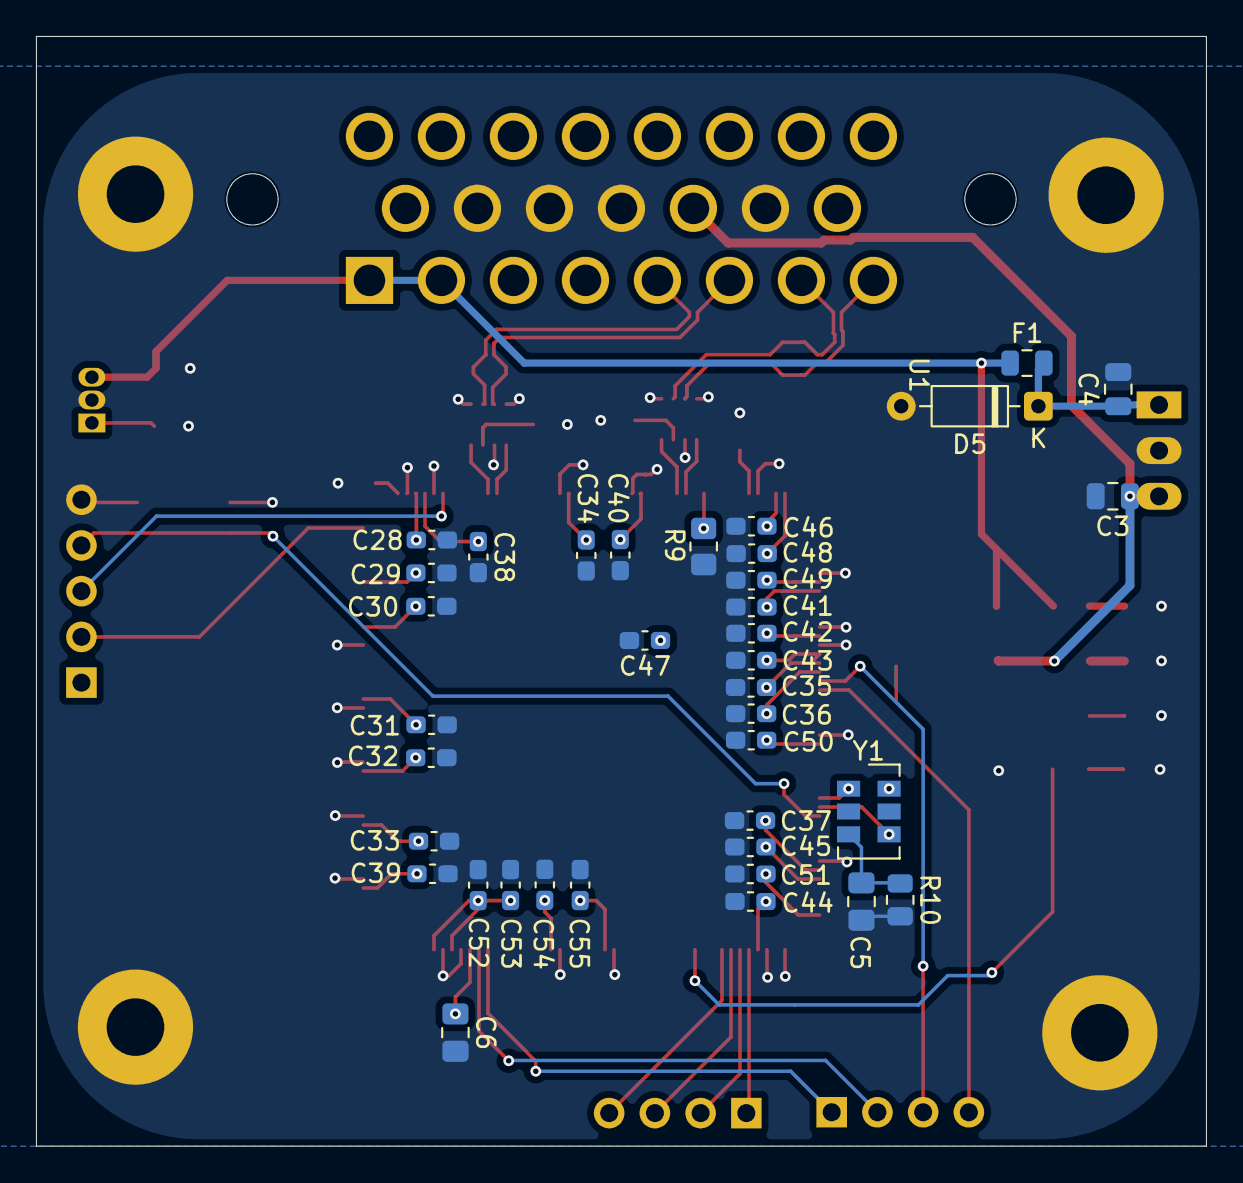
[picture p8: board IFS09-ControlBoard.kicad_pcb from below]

Board: 2 copper layers, 65.0 x 61.6 mm, 74 parts (37 on the bottom side), 36 nets.
